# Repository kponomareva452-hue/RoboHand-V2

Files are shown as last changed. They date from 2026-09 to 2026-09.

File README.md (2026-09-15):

# RoboHand V2 (RH-2W)

<p align="center">
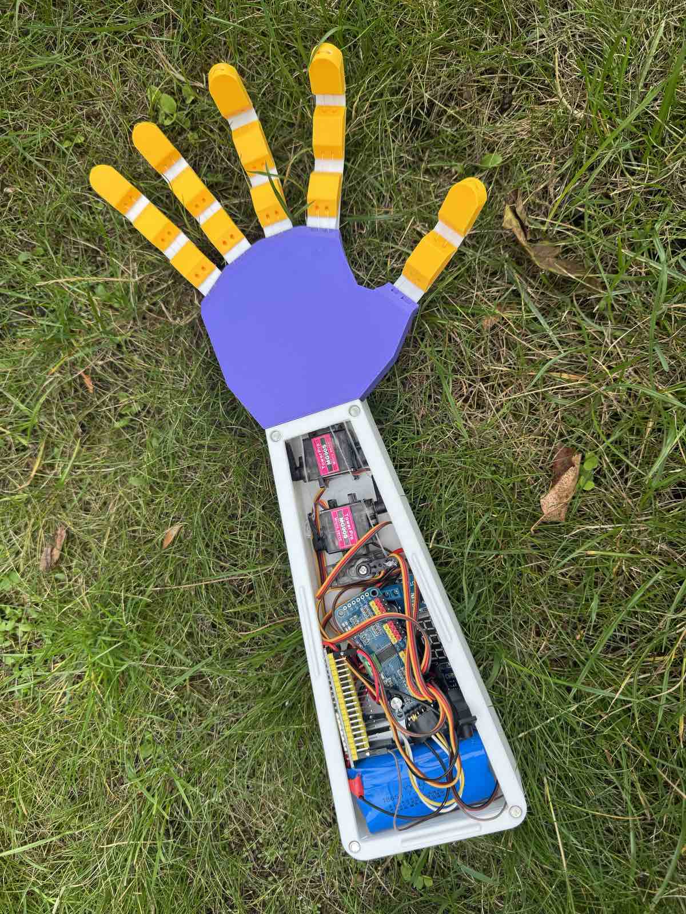
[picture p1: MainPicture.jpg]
RoboHand V2 on grass
  
</p>

3D-printed tendon-driven robotic hand with a **wearable Hand Controller**.

Five analog joysticks on a glove follow your fingers. An ESP32 on the glove sends the values over **ESP-NOW**. A second ESP32 in the forearm drives five **MG90S** servos through a **PCA9685**. Fingers close on fishing-line tendons and open on printed **TPU 95A** return links.

Print files: [RoboHandV2 with wearable HandController on MakerWorld](https://makerworld.com/en/models/3312121-robohandv2-with-wearable-handcontroller#profileId-3760254)

Version 1 (button remote): [MakerWorld](https://makerworld.com/en/models/2298640-robohand) · [GitHub](https://github.com/kponomareva452-hue/RoboHand)

---

## Photos

<p align="center">
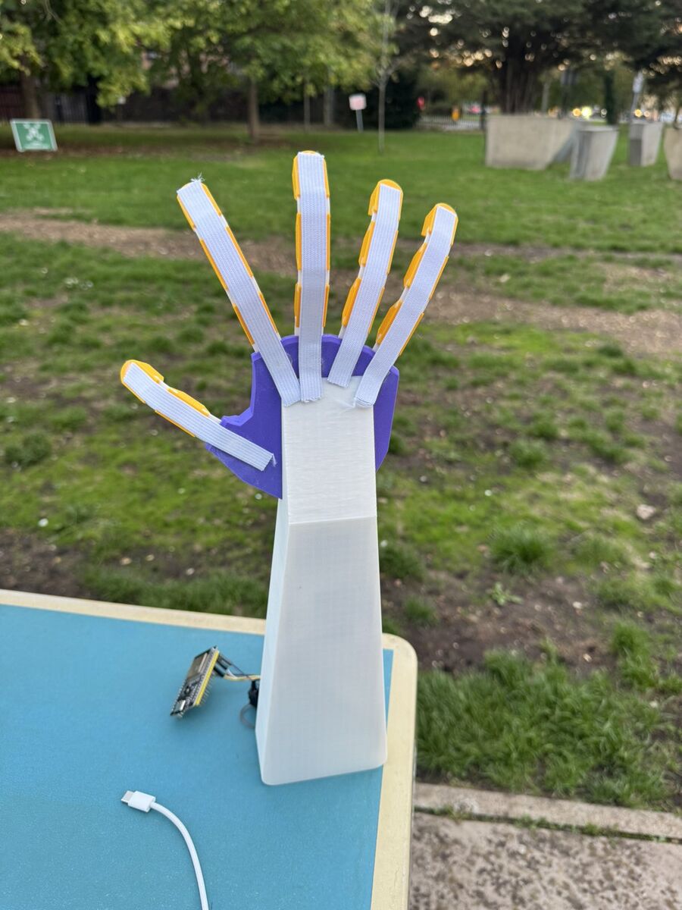
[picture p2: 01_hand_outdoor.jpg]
Standing outdoor
  
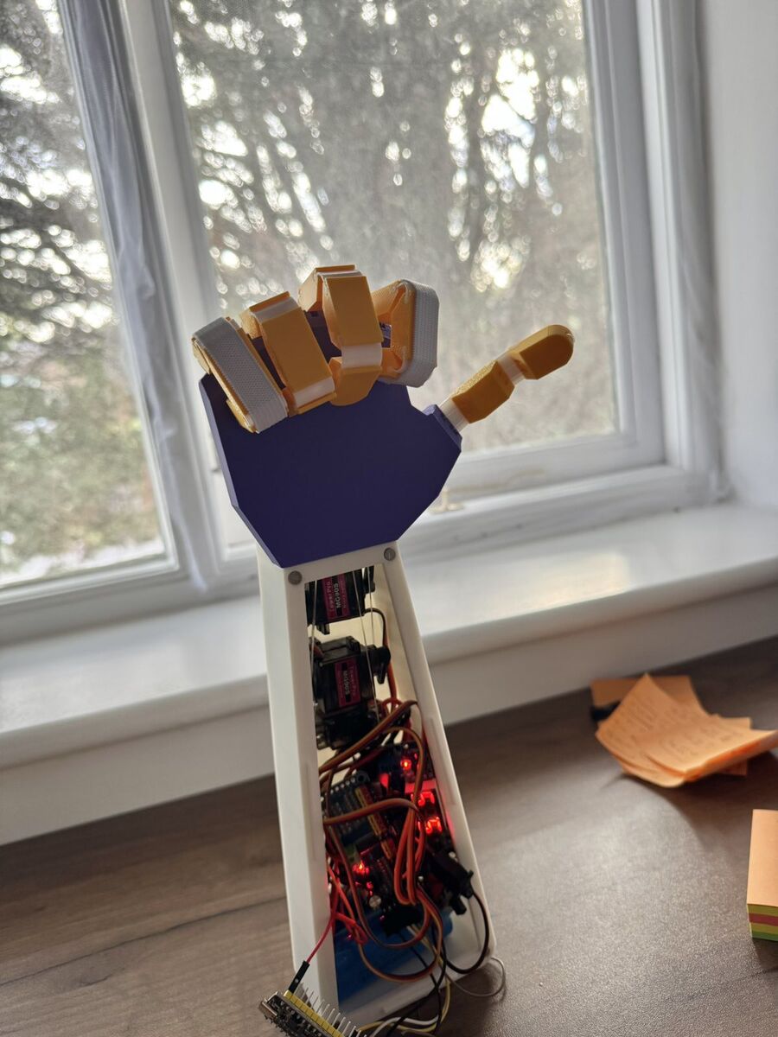
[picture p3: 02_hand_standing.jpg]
Standing hand
  
</p>

<p align="center">
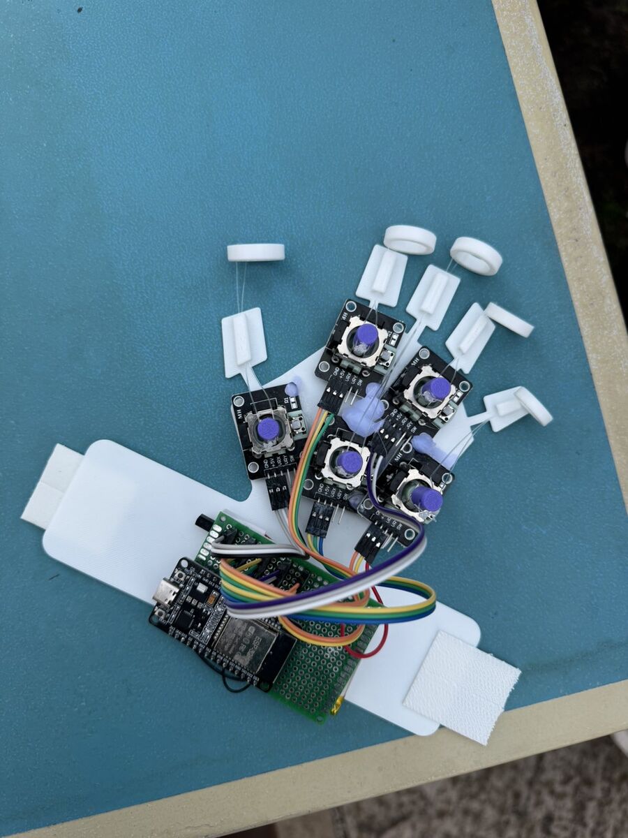
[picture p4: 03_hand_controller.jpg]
Hand Controller
  
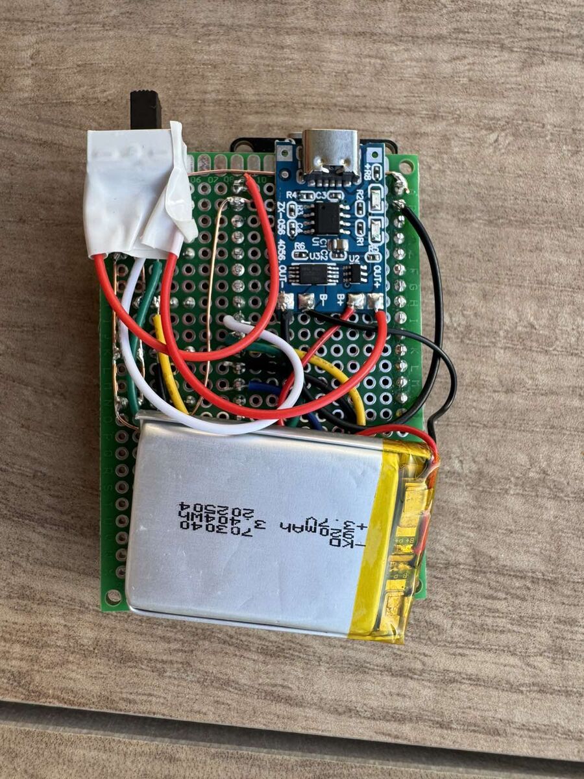
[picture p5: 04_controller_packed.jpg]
Packed controller
  
</p>

<p align="center">
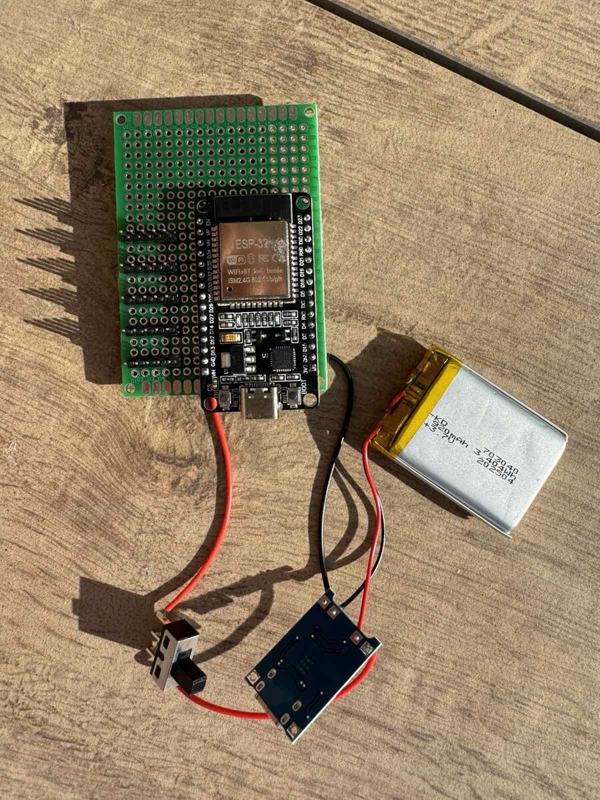
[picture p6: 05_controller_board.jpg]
Controller board
  
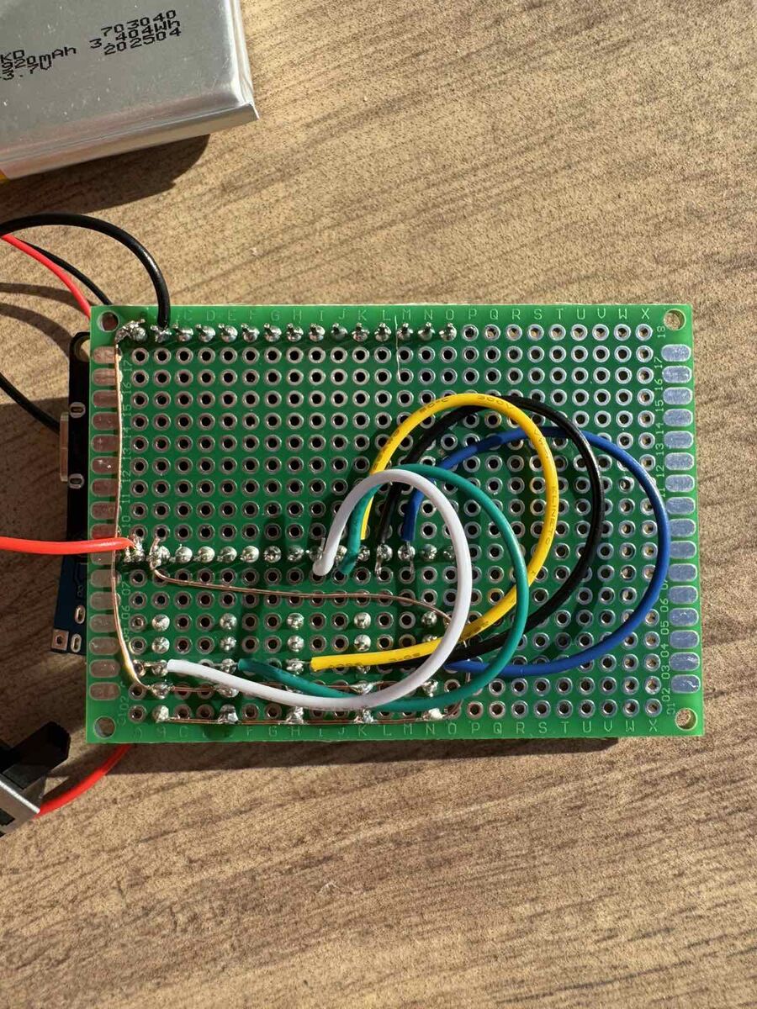
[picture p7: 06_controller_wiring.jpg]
Controller wiring
  
</p>

<p align="center">
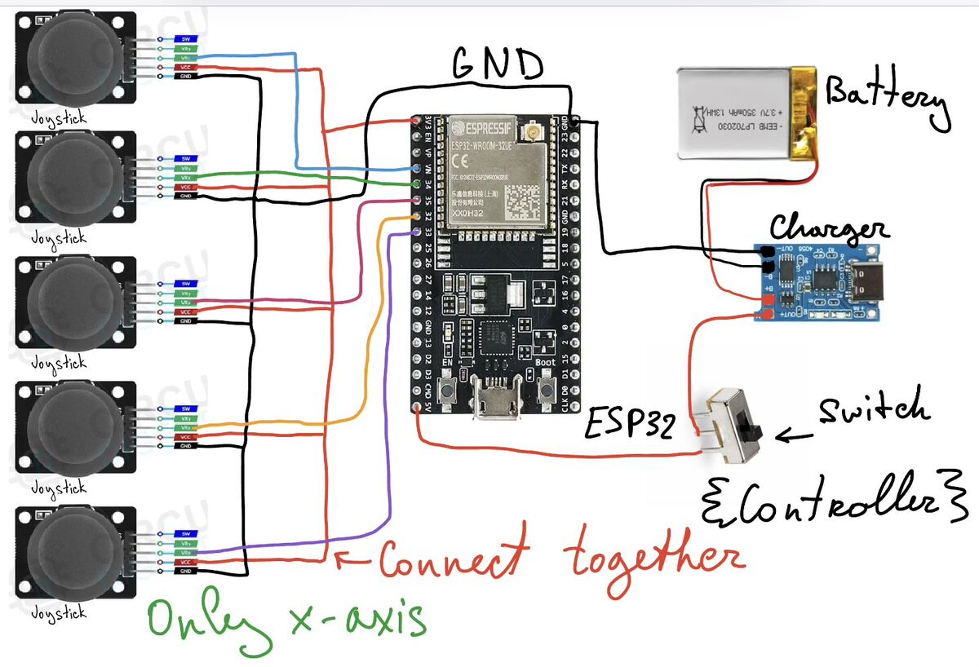
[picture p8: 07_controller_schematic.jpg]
Controller schematic
  
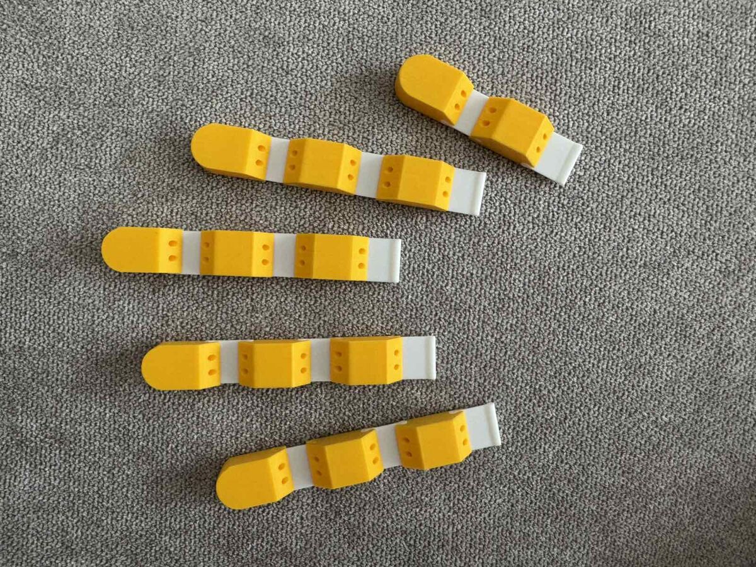
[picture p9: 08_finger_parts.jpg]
Finger parts
  
</p>

<p align="center">
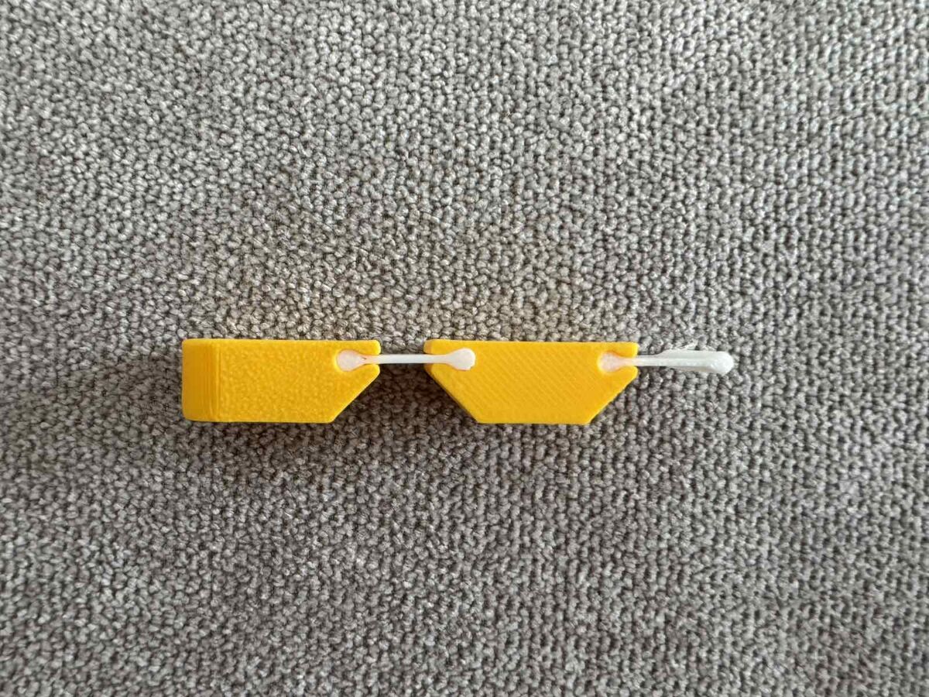
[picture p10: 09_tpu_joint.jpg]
TPU joint
  
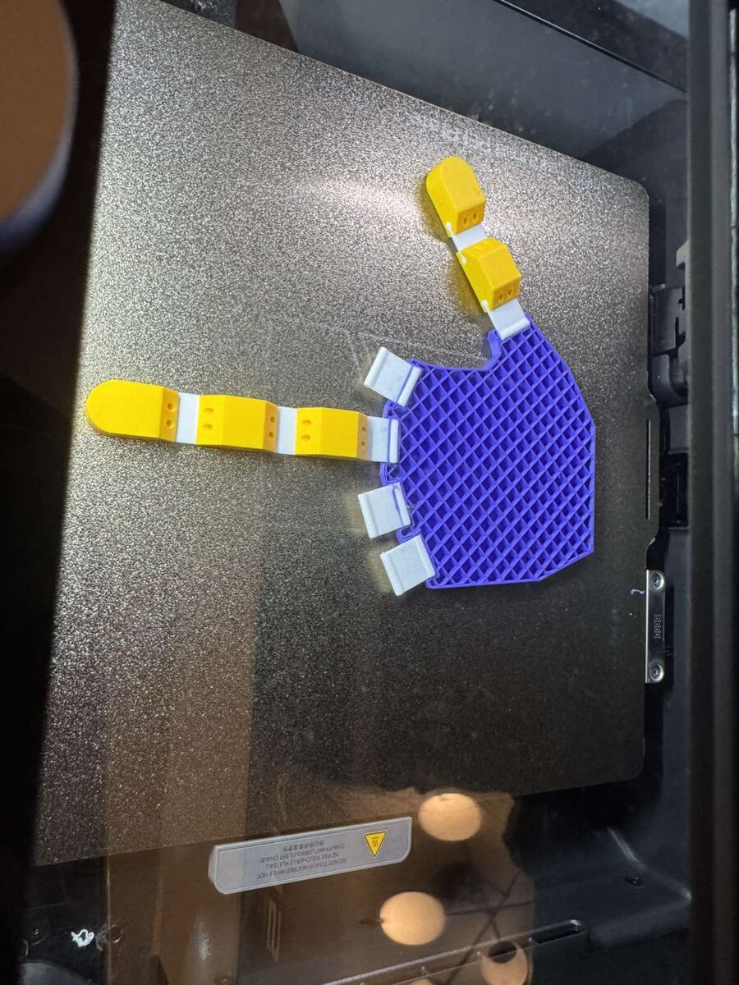
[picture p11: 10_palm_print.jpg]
Palm print
  
</p>

<p align="center">
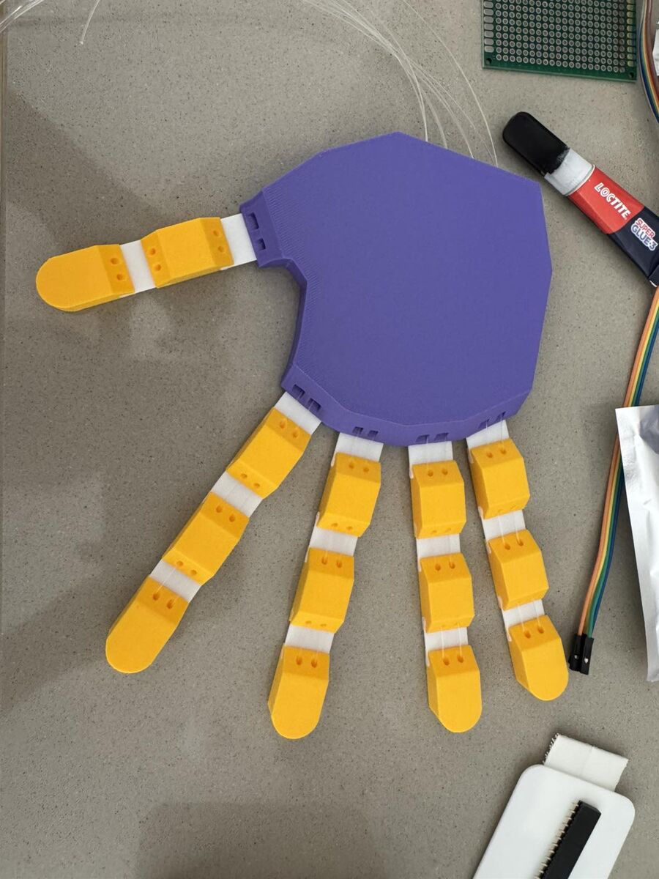
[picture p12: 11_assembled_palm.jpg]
Assembled palm
  
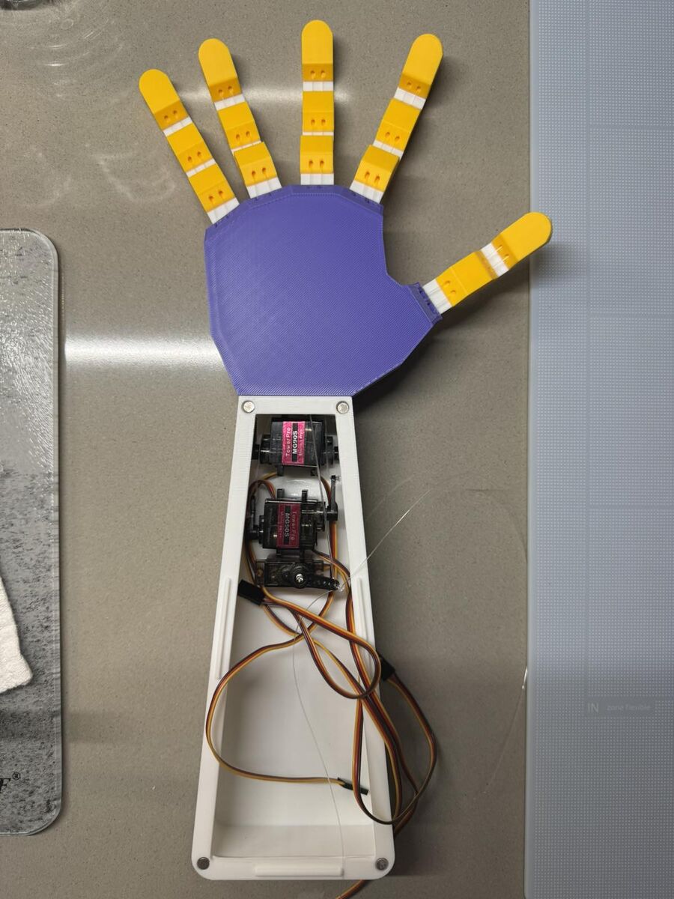
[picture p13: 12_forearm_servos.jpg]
Forearm servos
  
</p>

<p align="center">
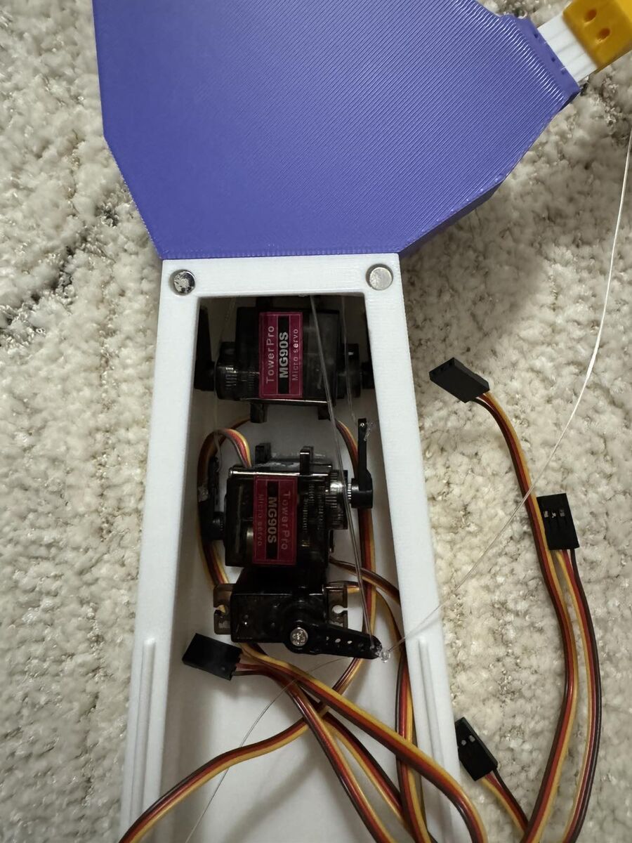
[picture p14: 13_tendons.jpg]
Tendons
  
</p>

---

## What is in this repo

| File | Board | Job |
|---|---|---|
| `firmware/RoboHand_V2_Controller_Sender/` | Glove ESP32 | Read 5 joysticks, send ESP-NOW |
| `firmware/RoboHand_V2_Hand_Receiver/` | Hand ESP32 | Receive packet, drive PCA9685 |
| `firmware/RoboHand_ServoCalibrator/` | Hand ESP32 | Live pulse test over Serial |
| `firmware/RoboHand_FingerValues/` | Hand ESP32 | Edit open/close values in code |
| `RoboHandV2.3mf` | — | Print plates |

---

## HandController pins

X-axis only. VCC = **3V3**. Do not put 5 V on the joysticks.

| Finger | GPIO |
|---|---|
| Thumb | 33 |
| Index | 32 |
| Middle | 35 |
| Ring | 34 |
| Pinky | 39 |

Power on the glove: 3.7 V LiPo to USB-C charger board to switch to ESP32 **5V** pin. Common GND.

---

## Hand wiring

- 7.4 V Li-ion (Deans T-plug) to 3 A fuse to switch to **LM2596** set to about 6 V
- LM2596 output to PCA9685 **V+** and a 1000 µF capacitor
- Hand ESP32 from a USB power bank, not from the servo rail
- I2C: SDA **21**, SCL **22**, PCA9685 address `0x40`
- Servos on channels **0-4** (Thumb to Pinky)
- Thumb, Ring, Pinky are reversed in `invert[]`

---

## Flash order

1. Arduino IDE, ESP32 board package, library **Adafruit PWM Servo Driver**.
2. Upload the receiver to the hand ESP32. Open Serial at 115200. Copy the printed MAC.
3. Paste that MAC into `receiverMac[]` in the sender.
4. Upload the sender to the glove.
5. If a servo buzzes, power off and shrink `openPulse` / `closePulse`.

Safe pulse window for MG90S at 50 Hz: about **90-560**. Start smaller.

Print: PETG bones, TPU 95A return links, 0.2 mm, 2 walls, 15% infill.

---

## Safety

Do not power five servos from the ESP32 5 V pin. Stop if a servo hums while it is not moving. Charge LiPo / 2S packs with a proper charger.

Firmware: MIT. Printed parts: use and remix with credit. Not a medical device.

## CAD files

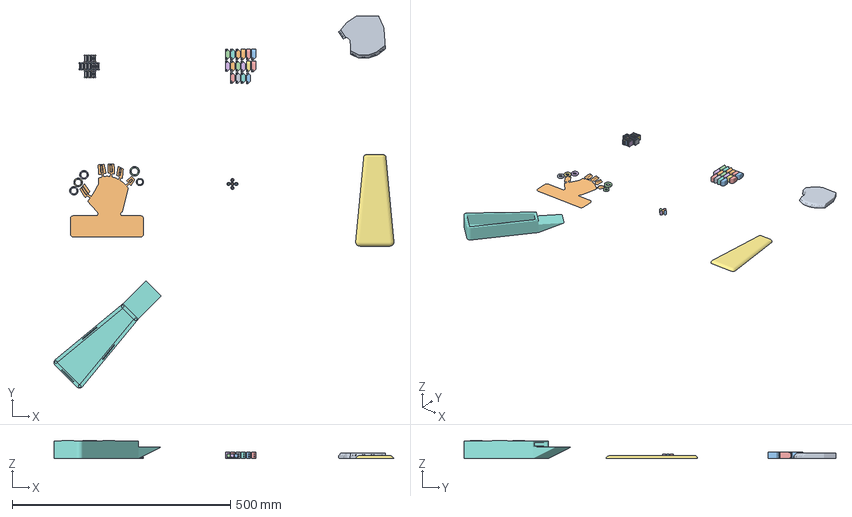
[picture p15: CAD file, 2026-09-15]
RoboHandV2.3mf
778.9 x 852.3 x 42.0 mm
joins.obj x 26
controllerfinal.obj
Part2.obj x 5
ring.obj x 5
Part1.obj x 11
Palmfinal.obj
thingForJoystick.obj x 5
coverArm.obj
arm.obj

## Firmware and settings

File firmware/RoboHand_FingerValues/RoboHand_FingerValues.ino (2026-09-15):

/*
  RoboHand V2 — per-finger servo values
  ESP32 + PCA9685 (0x40) + 5x MG90S

  Edit the numbers in FINGER VALUES, upload, watch the hand.
  Serial Monitor: 115200

  V2 mounting: Thumb, Ring, Pinky reversed in hardware.
  Put the pulse that actually OPENS that finger in openPulse,
  and the pulse that actually CLOSES it in closePulse.
  Do not power servos from the ESP32.
*/

#include <Wire.h>
#include <Adafruit_PWMServoDriver.h>

Adafruit_PWMServoDriver pwm = Adafruit_PWMServoDriver(0x40);

enum { THUMB = 0, INDEX = 1, MIDDLE = 2, RING = 3, PINKY = 4 };
const int SERVO_COUNT = 5;

int openPulse[SERVO_COUNT] = {
  150, 150, 150, 150, 150
};

int closePulse[SERVO_COUNT] = {
  500, 500, 500, 500, 500
};

const char* NAME[SERVO_COUNT] = {
  "Thumb", "Index", "Middle", "Ring", "Pinky"
};

const int CH[SERVO_COUNT] = {0, 1, 2, 3, 4};

const int TEST_MODE = 2;
const int CYCLE_MS  = 2000;

const int PULSE_MIN = 90;
const int PULSE_MAX = 560;

int clampPulse(int v) {
  if (v < PULSE_MIN) return PULSE_MIN;
  if (v > PULSE_MAX) return PULSE_MAX;
  return v;
}

void setFinger(int finger, bool closed) {
  int pulse = closed ? closePulse[finger] : openPulse[finger];
  pulse = clampPulse(pulse);
  pwm.setPWM(CH[finger], 0, pulse);
}

void setAll(bool closed) {
  for (int i = 0; i < SERVO_COUNT; i++) {
    setFinger(i, closed);
  }
}

void printValues() {
  Serial.println();
  Serial.println("finger   ch   OPEN  CLOSE");
  for (int i = 0; i < SERVO_COUNT; i++) {
    Serial.printf("%-7s  %d   %4d  %4d\n",
                  NAME[i], CH[i], openPulse[i], closePulse[i]);
  }
}

void setup() {
  Serial.begin(115200);
  delay(300);
  Wire.begin(21, 22);
  pwm.begin();
  pwm.setPWMFreq(50);
  delay(200);
  printValues();
  if (TEST_MODE == 1) {
    Serial.println("Holding CLOSE");
    setAll(true);
  } else {
    Serial.println("Holding OPEN");
    setAll(false);
  }
}

void loop() {
  if (TEST_MODE != 2) return;
  Serial.println("CLOSE");
  setAll(true);
  delay(CYCLE_MS);
  Serial.println("OPEN");
  setAll(false);
  delay(CYCLE_MS);
}

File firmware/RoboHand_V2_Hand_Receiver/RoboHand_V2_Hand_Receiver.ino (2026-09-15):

/*
  RoboHand V2 — hand receiver (ESP-NOW + PCA9685)
  Board: ESP32 inside the forearm
  Servos: 5x MG90S on PCA9685 channels 0-4
  Serial: 115200

  Edit openPulse / closePulse after calibration.
  invert[] = true means the horn is mounted the other way
  (Thumb, Ring, Pinky on V2).
*/

#include <WiFi.h>
#include <esp_now.h>
#include <Wire.h>
#include <Adafruit_PWMServoDriver.h>

Adafruit_PWMServoDriver pwm = Adafruit_PWMServoDriver(0x40);

const int SERVO_COUNT = 5;
const char* NAME[SERVO_COUNT] = {"Thumb", "Index", "Middle", "Ring", "Pinky"};
const int CH[SERVO_COUNT] = {0, 1, 2, 3, 4};

int openPulse[SERVO_COUNT]  = {150, 150, 150, 150, 150};
int closePulse[SERVO_COUNT] = {500, 500, 500, 500, 500};

int joyOpen[SERVO_COUNT]  = {1960, 1960, 1960, 1960, 1960};
int joyClose[SERVO_COUNT] = {800, 800, 800, 800, 800};

bool invert[SERVO_COUNT] = {true, false, false, true, true};

const int PULSE_MIN = 90;
const int PULSE_MAX = 560;

typedef struct __attribute__((packed)) {
  uint16_t raw[5];
} GloveData;

volatile GloveData incoming;
volatile bool gotPacket = false;

int clampPulse(int v) {
  if (v < PULSE_MIN) return PULSE_MIN;
  if (v > PULSE_MAX) return PULSE_MAX;
  return v;
}

int mapConstrained(int x, int inA, int inB, int outA, int outB) {
  if (inA == inB) return outA;
  long v = (long)(x - inA) * (outB - outA) / (inB - inA) + outA;
  if (outA < outB) {
    if (v < outA) v = outA;
    if (v > outB) v = outB;
  } else {
    if (v > outA) v = outA;
    if (v < outB) v = outB;
  }
  return (int)v;
}

void applyFinger(int i, uint16_t raw) {
  int outOpen  = invert[i] ? closePulse[i] : openPulse[i];
  int outClose = invert[i] ? openPulse[i]  : closePulse[i];
  int pulse = mapConstrained(raw, joyOpen[i], joyClose[i], outOpen, outClose);
  pwm.setPWM(CH[i], 0, clampPulse(pulse));
}

#if defined(ESP_NOW_MAX_DATA_LEN)
void onReceive(const esp_now_recv_info_t *info, const uint8_t *data, int len) {
#else
void onReceive(const uint8_t *mac, const uint8_t *data, int len) {
#endif
  if (len < (int)sizeof(GloveData)) return;
  memcpy((void*)&incoming, data, sizeof(GloveData));
  gotPacket = true;
}

void setup() {
  Serial.begin(115200);
  Wire.begin(21, 22);
  pwm.begin();
  pwm.setPWMFreq(50);
  delay(200);

  for (int i = 0; i < SERVO_COUNT; i++) {
    pwm.setPWM(CH[i], 0, clampPulse(openPulse[i]));
  }

  WiFi.mode(WIFI_STA);
  WiFi.disconnect();
  Serial.print("Hand MAC (paste into sender): ");
  Serial.println(WiFi.macAddress());

  if (esp_now_init() != ESP_OK) {
    Serial.println("ESP-NOW init failed");
    return;
  }
  esp_now_register_recv_cb(onReceive);
  Serial.println("Hand receiver ready");
}

void loop() {
  if (!gotPacket) return;
  gotPacket = false;
  GloveData d;
  noInterrupts();
  d = incoming;
  interrupts();
  for (int i = 0; i < SERVO_COUNT; i++) {
    applyFinger(i, d.raw[i]);
  }
}

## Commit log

2026-09-15 Add servo calibrator and finger-value test sketches
2026-09-15 Add live servo calibrator sketch
